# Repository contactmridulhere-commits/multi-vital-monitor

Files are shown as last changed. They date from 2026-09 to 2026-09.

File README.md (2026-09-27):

# Multi-Vital Monitor

An ESP32-based vital signs monitor with a live ECG trace, built from discrete
sensor modules on a 320x240 SPI TFT.

Measures heart rate two independent ways and cross-checks them, derives heart
rate variability and respiration rate from the same signals, and reports
temperature and relative alcohol response.

<p align="center">
  The finished monitor showing heart rate, SpO2, temperature, alcohol response, HRV and a live ECG trace
</p>

**Videos:** [All-in-one medical device](https://youtu.be/q9Ee2mhGdnA) · [All-in-one health monitor](https://youtu.be/jfgkhnGlEpk)

---

The firmware is built around a strict rule: every displayed number is either
measured or absent. Nothing is smoothed into existence, no stale value is left
on screen to age quietly, and anything without a valid measurement shows `--`.

---

## What it measures

| Metric | Source | Notes |
|---|---|---|
| Heart rate | ECG R-peaks, PPG as fallback | Shows which source, and flags disagreement |
| HRV (RMSSD, SDNN, pNN50) | ECG R-R intervals | Needs 30 accepted intervals first |
| SpO2 | MAX30102 red/IR ratio | Uncalibrated until fitted |
| Respiration rate | PPG baseline modulation | Least reliable output; needs a still subject |
| Perfusion index | PPG AC/DC | Signal-quality gate for the PPG metrics |
| Surface temperature | MLX90614 with field-of-view correction | Surface, not core |
| Alcohol response | MQ3, Rs/R0 against clean-air baseline | Relative only |
| Supply rail | AD8232 reference level | Trend indicator, no extra components |

---

## Hardware

| Part | Role |
|---|---|
| ESP32 devkit (classic, dual core) | Controller |
| 2.4" 320x240 SPI TFT (ILI9341-class) | Display |
| MAX30102 | Pulse oximetry, PPG |
| MLX90614 | Non-contact IR temperature |
| AD8232 breakout | Single-lead ECG front end |
| MQ3 | Alcohol vapour sensor |

### Wiring

<p align="center">
  Wiring diagram
  ESP32 pin assignments
</p>

A printable version is in [Circuit.pdf](Circuit.pdf).

**Display (SPI)** — set in TFT_eSPI's `User_Setup.h`, not in the sketch:

| Signal | GPIO |
|---|---|
| CS | 5 |
| DC | 16 |
| RST | 17 |
| SCK | 18 |
| MOSI | 15 |

**MAX30102** on I2C bus 0:

| Signal | GPIO |
|---|---|
| SDA | 21 |
| SCL | 22 |

**MLX90614** on I2C bus 1:

| Signal | GPIO |
|---|---|
| SDA | 25 |
| SCL | 26 |

**AD8232:**

| Signal | GPIO |
|---|---|
| OUTPUT | 33 (ADC1) |
| LO+ | 35 |
| LO- | 32 |
| SDN | not connected |

**MQ3:**

| Signal | GPIO |
|---|---|
| AOUT | 39 (ADC1) |

### Wiring notes

- **GPIO 34, 35, 36 and 39 are input-only** on the classic ESP32. They have no
  output driver and no internal pull-ups. The AD8232's SDN line is deliberately
  left unconnected — the breakout holds it high on its own.
- **GPIO 15 is a strapping pin.** It has an internal pull-up and boots high,
  which is fine. Do not tie it externally low or the board will not boot.
- **Both analog inputs are on ADC1** (33 and 39). ADC2 is unusable while WiFi
  is active, so this arrangement leaves the radio available for future use.
- **MOSI on GPIO 15 goes through the GPIO matrix**, not IO_MUX, which caps SPI
  around 40 MHz. Moving MOSI to GPIO 23 unlocks IO_MUX and 80 MHz if you ever
  need faster redraw.
- **Check your MQ3 module's output range.** Many run the heater from 5 V and
  can swing the analog output above 3.3 V. Use a divider if yours does.

---

## Libraries

Install through the Arduino Library Manager:

- `TFT_eSPI` by Bodmer
- `MAX3010x` by eepj
- `Adafruit MLX90614`

Each carries its own license: see [Credits](#credits).

---

## Build and flash

1. Install the ESP32 board package in the Arduino IDE.
2. Install the three libraries above.
3. Configure `TFT_eSPI/User_Setup.h` for your panel and the SPI pins listed
   above.
4. Open `Multi-Vital-device.ino`, select your ESP32 board, and upload. (The Arduino IDE may offer to move
   it into a folder of the same name; accept, and keep `filters.h` next to it.)
5. Open the serial monitor at **115200** and type `help`.

`filters.h` must sit in the same folder as the sketch.

---

## Configuration

All at the top of the sketch.

### Display orientation

```c
#define TFT_ROTATION      1     // 1 or 3 = landscape, 0 or 2 = portrait
#define LAYOUT_PORTRAIT   0     // set to 1 for rotation 0 or 2
```

Every dimension re-derives from these two. Nothing else hardcodes a pixel.

| Orientation | Rotation | LAYOUT_PORTRAIT |
|---|---|---|
| Landscape | 1, or 3 for upside down | 0 |
| Portrait | 0, or 2 for upside down | 1 |

**Verify your panel matches.** Add this after `tft.init()`:

```c
Serial.printf("panel %dx%d, layout expects %dx%d %s\n",
              tft.width(), tft.height(), SCR_W, SCR_H,
              (tft.width() == SCR_W && tft.height() == SCR_H) ? "OK" : "*** MISMATCH ***");
```

A mismatch draws the layout partly off-screen, which looks exactly like a
broken waveform.

### Mains frequency

```c
#define MAINS_HZ  50.0f    // 50 for India/EU, 60 for the Americas
```

Set this correctly. Mains hum survives the low-pass and is then amplified by the
R-peak detector's derivative stage, which walks the detected peak position by
several samples per beat and puts a floor of roughly 25 ms under RMSSD, inside
the physiological range, so HRV becomes noise wearing a number.

### ECG grid

```c
#define ECG_SHOW_VGRID  0    // 1 adds vertical time divisions
```

Vertical divisions are 16 columns apart, which at 83.3 columns/second is 192 ms
, close to a clinical monitor's 200 ms major division, but not equal to it. Do
not measure intervals off the screen assuming 200.

---

## First run

1. Power on. The boot screen reports the reset reason, sensor detection, free
   heap, and sprite allocation. A `BROWNOUT` reset means a power problem, not a
   firmware one.
2. **Leave it powered for the MQ3.** The heater needs 90 seconds from cold, then
   20 seconds of clean air to set its baseline. A sensor stored unpowered for
   months needs far longer — expect a day or two before its baseline settles.
3. **Attach the ECG electrodes to skin**, not just to the board. The display
   says `no ECG signal - check pads` when the leads are connected but nothing
   cardiac is coming through.
4. **Wait about 11 seconds** after the leads connect. The ECG display gain is
   measured over seconds 6 to 11 and then held. Fitting earlier measures the
   baseline tracker converging rather than the heartbeat.
5. Check the status bar reads `250/100Hz`. Those are the measured ECG and PPG
   sample rates. If they drift, the filter corner frequencies are wrong and
   every derived number is suspect — which is why they are on screen
   permanently.

---

## Serial console

115200 baud. `help` lists everything.

| Command | Effect |
|---|---|
| `status` | Full diagnostic dump |
| `spo2 ref <pct>` | Record current R ratio against a reference oximeter reading |
| `spo2 fit` | Least-squares fit and save (needs 3+ spread-out points) |
| `spo2 clear` | Discard collected points and stored coefficients |
| `temp ref <degC>` | Solve the field-of-view fill fraction from a known surface |
| `rail ref <volts>` | Set ADC full scale from a multimeter reading of 3V3 |
| `mq3 zero` | Re-zero the clean-air baseline |
| `gain auto` | Re-measure the ECG display gain over 6 s |
| `gain <counts/px>` | Fix the ECG display gain by hand |
| `gain show` | Report the current ECG gain |
| `raw on` / `raw off` | Stream slow-sensor values |

Calibration persists to NVS.

### Calibrating SpO2 properly

Hold a reference pulse oximeter on one finger and this device on another. Run
`spo2 ref <value>` at three or more genuinely different saturation levels, a
short breath-hold will move it. Then `spo2 fit`. The display switches from
`estimate only` to `calibrated`.

Without this, the SpO2 number is a placeholder formula.

---

## How it works

**Two FreeRTOS tasks on core 0, one on core 1.** `ecgTask` runs a fixed 250 Hz
tick and touches nothing that can block — no I2C, no SPI. `sensorTask` owns all
I2C and is paced by the MAX30102 itself. `renderTask` draws at 50 Hz on core 1.

That separation is the whole point. Reading the MAX30102 FIFO blocks for around
10 ms, so any design that drains it inside the ECG loop paces the ECG at the
PPG's rate, putting every filter corner frequency roughly ten times too low.

**ECG chain, detection:** 50/60 Hz notch, 5-15 Hz band-pass, five-point
derivative, square, 100 ms moving-window integration, adaptive dual threshold
with a 200 ms refractory. Peak position is refined by parabolic interpolation.
The integrator lags the true R peak by a constant amount, which cancels in R-R
intervals.

**ECG chain, display:** separate path — notch, two-pole 30 Hz low-pass, minus a
slowly tracked centre. No high-pass: the AD8232 already high-passes internally,
so its output arrives centred at VS/2. Adding another one is redundant and, as a
biquad starting from zero state, it rings for a second on the initial DC step.

**Display gain is measured once and held**, like a hospital monitor, rather than
adapting continuously. Continuous auto-scaling means the gain moves while you
are looking at the trace and you can never tell whether the signal changed or
the scale did.

**Sweep rendering.** The trace stays still and a cursor moves across it with a
blank gap erasing ahead. Only the new columns are pushed — about 4 KB per
update instead of redrawing the whole strip.

---

## Troubleshooting

| Symptom | Check |
|---|---|
| Layout clipped or partly off screen | Panel size vs `LAYOUT_PORTRAIT` — use the printf above |
| Status bar not showing `250/100Hz` | `status` reports the FreeRTOS tick rate; the ECG task needs at least 250 Hz |
| ECG box shows `no ECG signal` | Electrodes on skin? Dried gel? `status` reports `qrs amp` and `snr` |
| ECG trace tiny or off-centre | `gain auto`, and wait the full 11 s |
| HRV stuck at `0/30` | R-peaks not being detected — same checks as `no ECG signal` |
| Alcohol stuck on `baseline n/20` | Still capturing clean-air baseline; needs 20 s after warm-up |
| Temperature shows `no target` | Aim at skin from 2-5 cm; a room-temperature surface is correctly rejected |
| Random resets | `status` reports the reset reason; `BROWNOUT` means power |

---

## Enclosure

The five panels of the handheld case are in [`hardware/enclosure`](hardware/enclosure) as STL files, ready to slice.

## Earlier version

The first build (early 2026) used one sketch per sensor on a 3.5-inch screen with USB-C charging.
Photos are in [`media/v1`](media/v1), and the original code is archived at
[All-in-one-medical-device](https://github.com/contactmridulhere-commits/All-in-one-medical-device).

<p align="center">
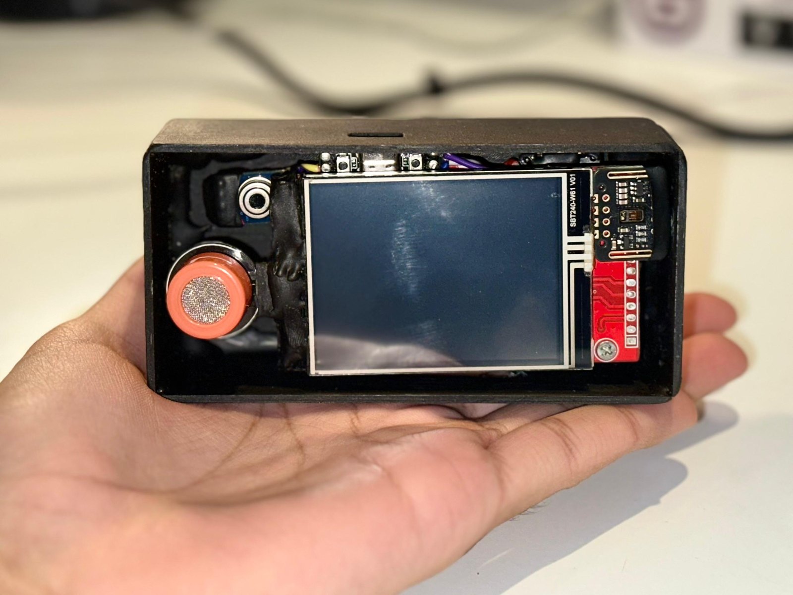
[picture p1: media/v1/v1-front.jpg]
Version 1 in hand
  
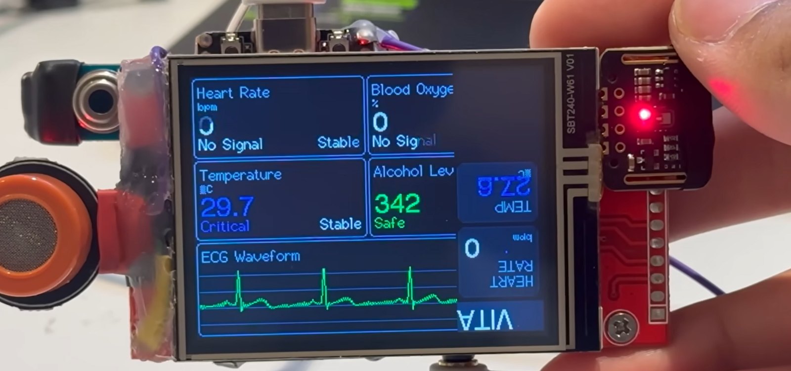
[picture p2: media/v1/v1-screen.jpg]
Version 1 screen
  
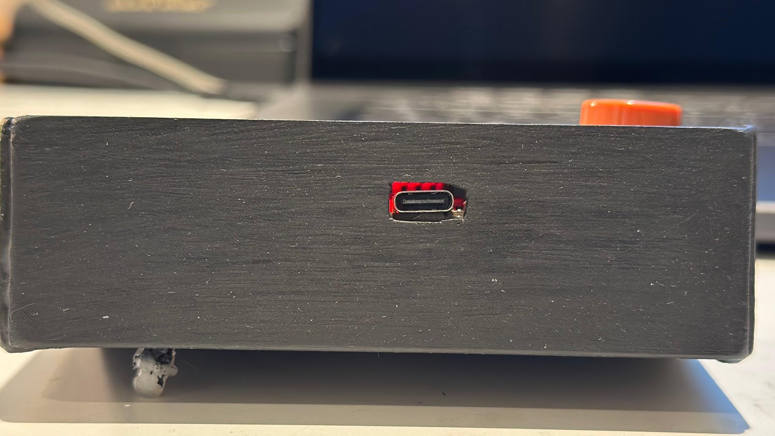
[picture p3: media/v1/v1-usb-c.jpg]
Version 1 USB-C charging port
  
</p>

## Credits

Built by Mridul Sharma and Kaushiki Shukla.

Mridul did most of the hardware build. Kaushiki guided the choice of tools and parts, and what to integrate.

Third-party libraries, each under its own license:

- [TFT_eSPI](https://github.com/Bodmer/TFT_eSPI) by Bodmer
- [MAX3010x](https://github.com/eepj/MAX3010x) by eepj
- [Adafruit MLX90614](https://github.com/adafruit/Adafruit-MLX90614-Library)

---

## License

MIT — see [LICENSE](LICENSE).

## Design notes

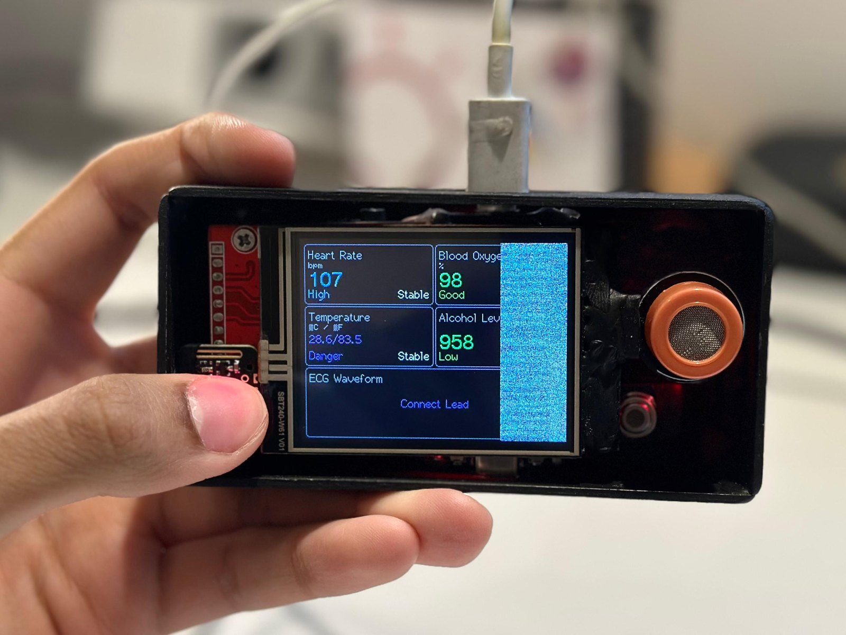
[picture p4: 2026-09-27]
media/v1/v1-readings.jpg

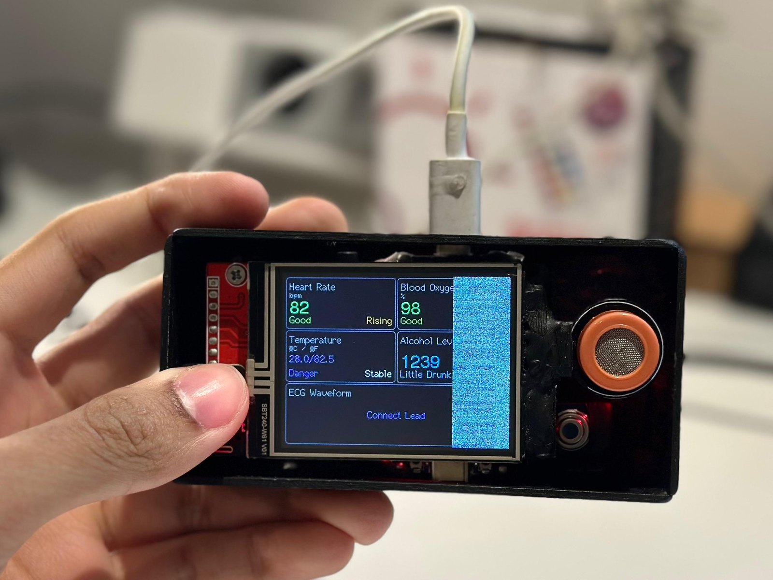
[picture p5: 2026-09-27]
media/v1/v1-live.jpg

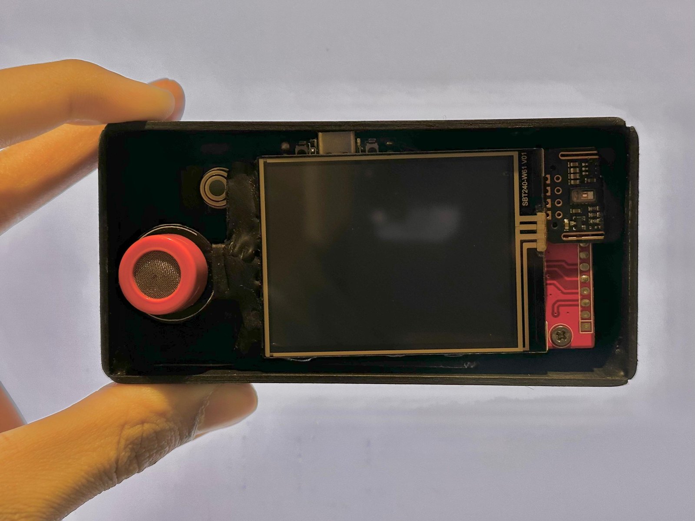
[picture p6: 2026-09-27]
media/v1/v1-boot.jpg

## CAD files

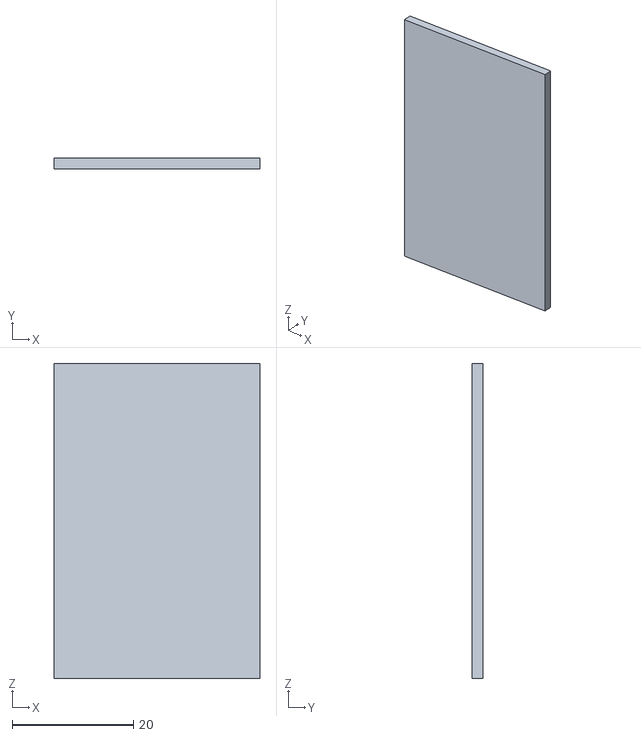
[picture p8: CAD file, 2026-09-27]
hardware/enclosure/enclosure-part-2.stl
34.0 x 1.75 x 52.0

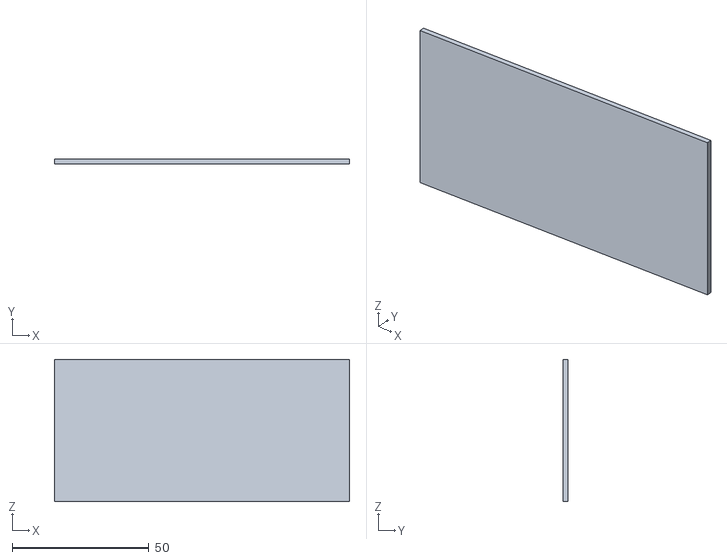
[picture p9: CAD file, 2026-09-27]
hardware/enclosure/enclosure-part-1.stl
108.0 x 1.75 x 52.0

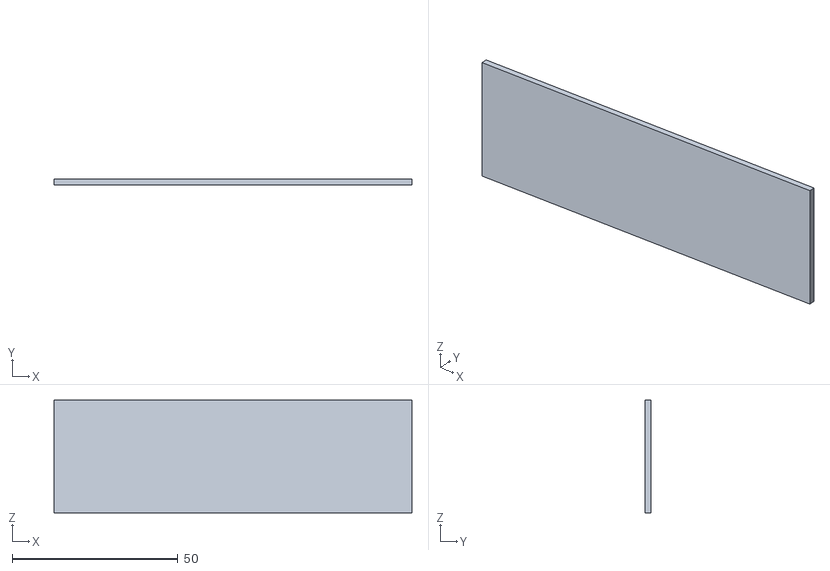
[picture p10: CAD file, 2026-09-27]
hardware/enclosure/enclosure-part-4.stl
108.0 x 1.75 x 34.0

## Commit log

2026-09-27 Bring over v1 build photos from All-in-one-medical-device
2026-09-27 Add the five enclosure panels as STL
    [enclosure-part-1.stl, enclosure-part-2.stl, enclosure-part-3.stl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]
2026-09-27 README: fix sketch name, show photos and wiring, add enclosure and v1 sections
